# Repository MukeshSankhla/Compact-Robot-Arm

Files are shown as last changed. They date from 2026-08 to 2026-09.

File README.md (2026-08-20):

# ESP32-Controlled 5-Axis Compact Robot Arm

Block Diagram

This project is a high-performance recreation and upgrade of the 3D-printable [Compact Robot Arm (Arduino) by Build Some Stuff](https://www.printables.com/model/818975-compact-robot-arm-arduino-3d-printed). While the original design utilized a passive analog mimic controller, this version leverages the **ESP32** microcontroller coupled with a **PCA9685 16-channel 12-bit PWM driver** to offer dual-mode operation: **tactile physical joystick control** and a **remote WiFi-based web dashboard** featuring a real-time responsive SVG forward-kinematics visualization.

---

## Table of Contents
1. [Key Features](#key-features)
2. [Project Architecture & Directory Structure](#project-architecture--directory-structure)
3. [Bill of Materials (BOM)](#bill-of-materials-bom)
4. [Circuit & Wiring Diagram](#circuit--wiring-diagram)
5. [Pin Mapping](#pin-mapping)
6. [Software Features & Logic](#software-features--logic)
7. [Web Interface & HTTP API](#web-interface--http-api)
8. [3D Printed Parts & Assembly Notes](#3d-printed-parts--assembly-notes)
9. [Getting Started & Installation](#getting-started--installation)
10. [Credits & Attribution](#credits--attribution)

---

## Key Features

- **Dual Control Modes**:
  - **Physical Analog Joysticks**: Tactile manipulation of joints with real-time speed adjustments, plus integrated buttons for quick-closing and opening the gripper.
  - **WiFi Web Dashboard**: Broadcasts an independent Access Point (AP). Hosts a modern, glassmorphism-themed dark-mode dashboard with virtual on-screen joysticks and slider states.
- **Real-Time Visual Representation**: The web interface calculates a 2D side-profile of the robot arm using basic forward kinematics (trigonometric representation of links) and renders it dynamically in a vector-based HTML5 SVG.
- **Smooth Servo Ease Motion**: Prevents violent jerks on startup and during the home command by stepping servo movements incrementally using a custom [`slowMove()`](file:///c:/Users/MAKERBRAINS/Downloads/Compact%20Robot%20Arm/Compact_Robot_Arm_Code/Compact_Robot_Arm_Code.ino#L108) routine.
- **Automatic Calibration**: Automatically samples ADC offsets on boot to establish center positions and deadzones, filtering out joystick noise and drift.
- **Clean Cable Management**: The structural parts are hollow, enabling clean routing of servo motor cables inside the arm segments to avoid twisting and external clutter.

---

## Project Architecture & Directory Structure

```
Compact Robot Arm/
├── BD.png                        # System Block Diagram
├── Circuit Connections.png       # Schematic and Wiring Diagram
├── CAD/                          # 18 STL files for 3D Printing
│   ├── Actuator Support A.stl
│   ├── Actuator Support B.stl
│   ├── Base Rotation Ring.stl
│   ├── Body1.stl
│   ├── Elbow Joint Shaft.stl
│   ├── Elbow Pivot Spacer.stl
│   ├── Forearm Housing Left.stl
│   ├── Forearm Housing Right.stl
│   ├── Gripper Blade A.stl
│   ├── Gripper Blade B.stl
│   ├── Inner Upper Arm.stl
│   ├── Motor Access Plate.stl
│   ├── Outer Upper Arm.stl
│   ├── Servo Mount Plate.stl
│   ├── Shoulder Actuator Case.stl
│   ├── Shoulder Cable Guard.stl
│   ├── Shoulder Mount Plate.stl
│   └── Shoulder Support Plate.stl
├── Compact_Robot_Arm_Code/
│   └── Compact_Robot_Arm_Code.ino # Main Arduino C++ sketch for ESP32
└── README.md                     # Project documentation (this file)
```

---

## Bill of Materials (BOM)

### Electronics
1. **Microcontroller**: ESP32 Development Board (30-pin or 38-pin version).
2. **Servo Controller**: Adafruit PCA9685 16-Channel 12-bit PWM I2C Driver.
3. **Servos**:
   - **4x MG996R (or MG995) metal gear high-torque servos** (for Base, Shoulder, Elbow, and Wrist rotation).
   - **1x MG90S (or SG90) micro servo** (for the Gripper mechanism).
4. **Controllers**: 2x Analog Joystick Modules (e.g., KY-023 dual-axis potentiometer joysticks with integrated push-buttons).
5. **Power Supply**: 5V DC power supply with at least 2A output. Servos drawing current simultaneously under load will cause an ESP32 brownout if underpowered.
---

## Circuit & Wiring Diagram

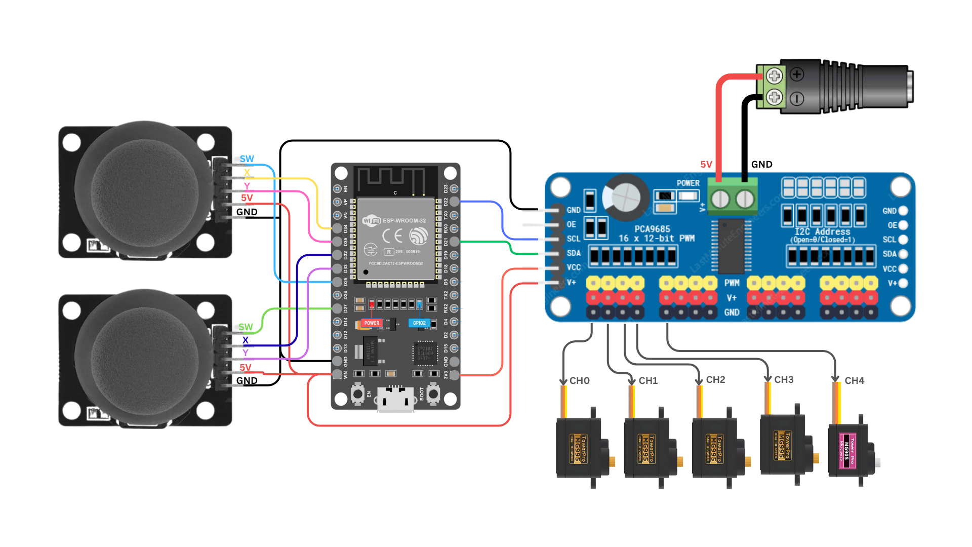
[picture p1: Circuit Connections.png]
Circuit Diagram


---

## Pin Mapping

The physical wiring between the ESP32 microcontroller, Joysticks, and the PCA9685 is configured as follows in the firmware:

### 1. ESP32 to PCA9685 (I2C Communication)
- **SDA** $\rightarrow$ **GPIO 21**
- **SCL** $\rightarrow$ **GPIO 22**
- **I2C Address**: `0x40` (Default)

### 2. PCA9685 Servo Channels
| Channel | Servo Label | Description |
| :---: | :--- | :--- |
| **0** | `M1_CH` | **Base Rotation Servo** (M1) |
| **1** | `M2_CH` | **Shoulder Servo** (M2) |
| **2** | `M3_CH` | **Elbow Servo** (M3) |
| **3** | `M4_CH` | **Wrist Servo** (M4) |
| **4** | `M5_CH` | **Gripper Fingers Servo** (M5) |

### 3. Joysticks to ESP32
| Joystick Module | Joystick Pin | ESP32 GPIO | Associated Action |
| :--- | :---: | :---: | :--- |
| **Joystick 1** | X-Axis | **GPIO 34** | Controls **Shoulder (M2)** |
| **Joystick 1** | Y-Axis | **GPIO 35** | Controls **Base (M1)** |
| **Joystick 1** | Button Switch (SW) | **GPIO 25** | **Opens Gripper** (M5 $\rightarrow$ 90°) |
| **Joystick 2** | X-Axis | **GPIO 32** | Controls **Elbow (M3)** |
| **Joystick 2** | Y-Axis | **GPIO 33** | Controls **Wrist (M4)** |
| **Joystick 2** | Button Switch (SW) | **GPIO 27** | **Closes Gripper** (M5 $\rightarrow$ 0°) |

---

## Software Features & Logic

The project software is loaded in [`Compact_Robot_Arm_Code.ino`](file:///c:/Users/MAKERBRAINS/Downloads/Compact%20Robot%20Arm/Compact_Robot_Arm_Code/Compact_Robot_Arm_Code.ino). Below are descriptions of key functional parts:

### 1. Joystick Calibration ([`calibrateJoysticks()`](file:///c:/Users/MAKERBRAINS/Downloads/Compact%20Robot%20Arm/Compact_Robot_Arm_Code/Compact_Robot_Arm_Code.ino#L156-L205))
On start-up, the ESP32 instructs the user to leave the joysticks untouched for 2 seconds. It takes 100 analog samples from the ADC channels, averages them, and saves the values as references (`J1X_CENTER`, `J1Y_CENTER`, etc.). This calibrates out unique hardware offset errors and centers.

### 2. Noise & Deadzone Filtering ([`joystick()`](file:///c:/Users/MAKERBRAINS/Downloads/Compact%20Robot%20Arm/Compact_Robot_Arm_Code/Compact_Robot_Arm_Code.ino#L212-L239))
Reads the joystick inputs and implements a deadzone filter (`#define DEADZONE 260`) to avoid micro-drifting when the stick is resting. The movement is normalized between `-1.0` and `1.0` using custom scales for asymmetrical potentiometer bounds.

### 3. Ease-in Easing Algorithm ([`slowMove()`](file:///c:/Users/MAKERBRAINS/Downloads/Compact%20Robot%20Arm/Compact_Robot_Arm_Code/Compact_Robot_Arm_Code.ino#L108-L132))
Avoids abrupt servo snap actions. The function divides a large motion request into tiny steps (`stepSize = 0.8f`) separated by micro delays (`msPerStep = 8`), moving the robot smoothly to the target position:
```cpp
void slowMove(uint8_t channel, float fromAngle, float toAngle, float stepSize = 0.8f, int msPerStep = 8)
```

---

## Web Interface & HTTP API

The ESP32 runs a local Web Server on port 80 and initializes an Access Point:
- **SSID**: `RobotArm-ESP32`
- **Password**: `12345678`
- **IP Address**: `192.168.4.1`

### UI Mechanics & Kinematics Engine
- **Canvas Joysticks**: Recreates absolute physical joystick layouts on the screen, bound to click, drag, and touch gestures.
- **Forward Kinematics (SVG Representation)**: In the web script, a 2D side-profile of the robot is drawn using joint lengths (`SEG = [80, 70, 30]`). When servo positions are requested, it updates the SVG elements:
  - Base translation ($M_1$) shifts the base laterally on the page, representing side-view perspective depth.
  - Shoulder ($M_2$), Elbow ($M_3$), Wrist ($M_4$), and Gripper ($M_5$) angles calculate trigonometric relative coordinate positions ($x, y$) for the joint pivots and finger tips, updating the lines and labels live.

### API Endpoints
The server handles the following endpoints:
- `GET /` : Serves the core HTML/CSS/JS page from flash (`MAIN_PAGE`).
- `GET /motor?m=<1-4>&a=<angle>` : Sets a specific joint's target angle (0 to 180 degrees).
- `GET /gripper?action=<open|close>` : Directly commands the gripper servo (90° for open, 0° for closed).
- `GET /home` : Initiates a slow, synchronized homing sequence for all joints.
- `GET /status` : Returns a JSON object containing the current coordinate states:
  ```json
  {"m1": 100.0, "m2": 0.0, "m3": 180.0, "m4": 90.0, "m5": 0.0}
  ```

---

## 3D Printed Parts & Assembly Notes

The custom STL files for the structural parts are stored under the [`CAD/`](file:///c:/Users/MAKERBRAINS/Downloads/Compact%20Robot%20Arm/CAD) directory:
- **Structural arms**: `Inner Upper Arm.stl`, `Outer Upper Arm.stl`, `Forearm Housing Left.stl`, `Forearm Housing Right.stl`
- **Support Plates**: `Shoulder Support Plate.stl`, `Shoulder Mount Plate.stl`, `Servo Mount Plate.stl`
- **Actuators**: `Shoulder Actuator Case.stl`
- **Gripper**: `Gripper Blade A.stl`, `Gripper Blade B.stl`

### Printing Recommendations
- **Material**: PLA 
- **Layer Height**: `0.2 mm`
- **Supports**: Enable support structures for overhang segments.

---

### Firmware Upload
1. Open the [Arduino IDE](https://www.arduino.cc/en/software).
2. Install the **ESP32 board support package** (`Tools > Board > Boards Manager`).
3. Install the **Adafruit PWM Servo Driver Library** from the Library Manager.
4. Open [`Compact_Robot_Arm_Code.ino`](file:///c:/Users/MAKERBRAINS/Downloads/Compact%20Robot%20Arm/Compact_Robot_Arm_Code/Compact_Robot_Arm_Code.ino).
5. Select your ESP32 board and the corresponding COM port.
6. Connect your ESP32 via USB and upload the sketch.

### Initial Boot & Control
1. **Calibrate**: Power on the circuit. Ensure the joysticks are resting centered. The onboard calibration will compute within 2 seconds.
2. **Homing**: The arm will automatically execute a slow home posture sequence to initialize position tracking safely.
3. **Local Control**: Move the physical joysticks to actuate the arm. Press Joystick 1's click switch to open the gripper, and Joystick 2's click switch to close it.
4. **WiFi Control**:
   - On a phone or laptop, scan for WiFi networks and connect to `RobotArm-ESP32` using password `12345678`.
   - Open a browser and navigate to `http://192.168.4.1`.
   - Control the arm using the interactive web dashboard.

---

## Credits & Attribution

- **Original Mechanical Design**: Kelton at [Build Some Stuff](https://www.printables.com/@buildsomestf_1924578).
- **Mechanical CAD/STL files**: Downloaded from the [Compact Robot Arm Printables Page](https://www.printables.com/model/818975-compact-robot-arm-arduino-3d-printed).
- **Firmware, Network Stack, & Web App Upgrade**: Recreated and modified to run on ESP32 + PCA9685 with a visual web server dashboard.

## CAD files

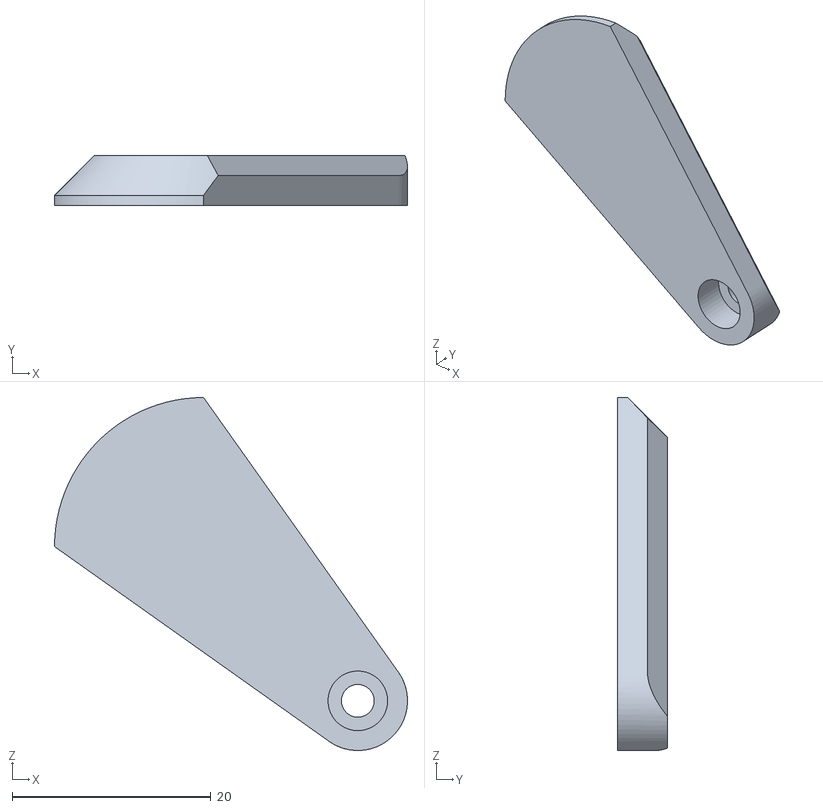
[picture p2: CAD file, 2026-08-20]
CAD/Gripper Blade A.stl
35.5 x 5.00 x 35.5

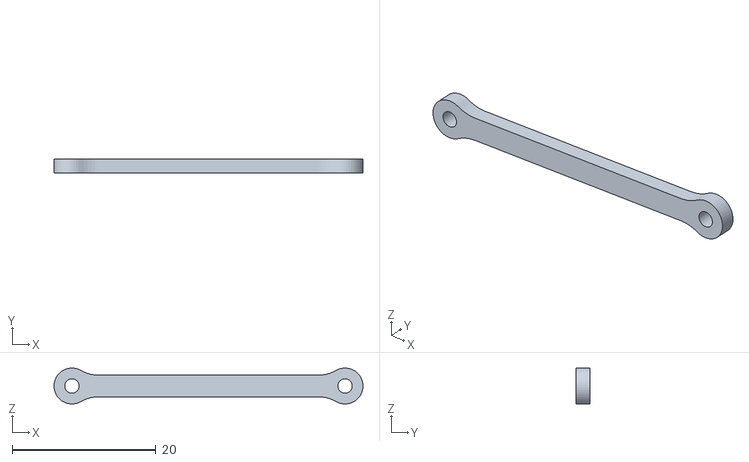
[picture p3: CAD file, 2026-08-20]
CAD/Body1.stl
43.0 x 2.00 x 4.99

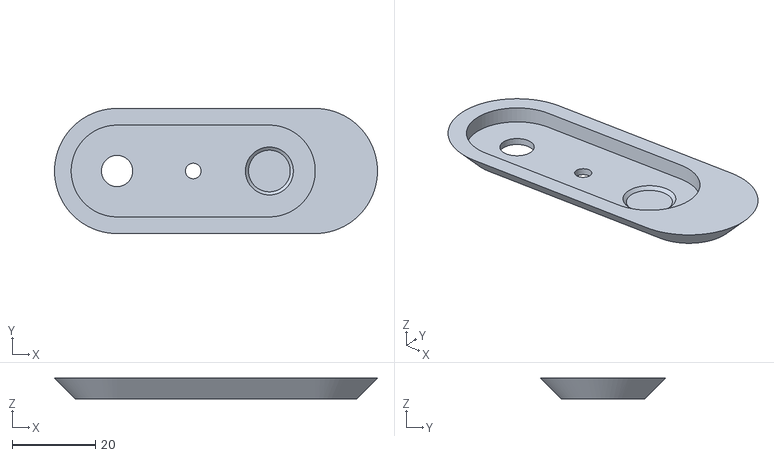
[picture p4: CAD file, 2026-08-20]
CAD/Elbow Pivot Spacer.stl
77.4 x 30.0 x 5.00

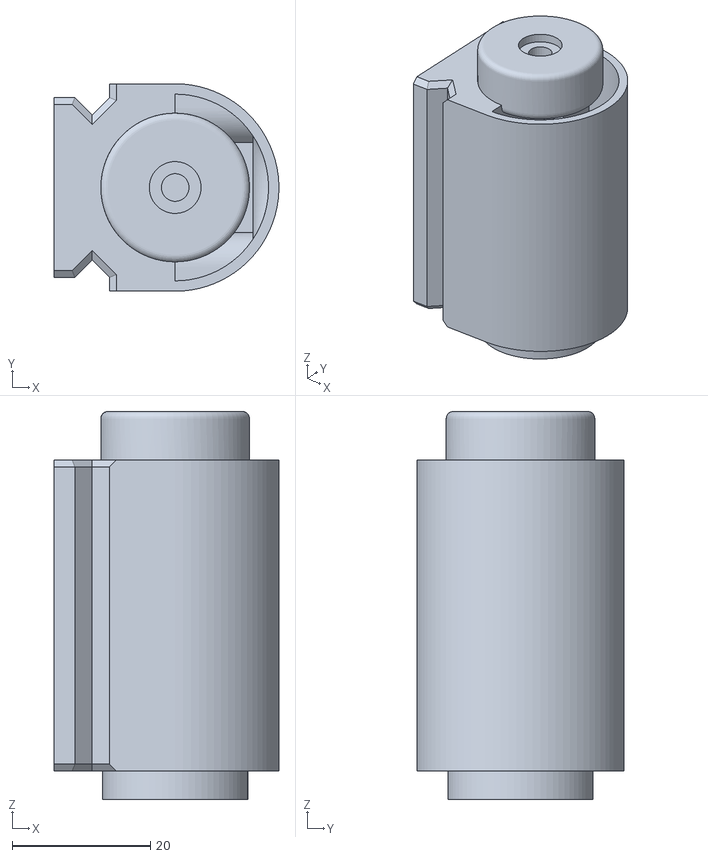
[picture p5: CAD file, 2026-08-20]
CAD/Elbow Joint Shaft.stl
32.5 x 30.0 x 56.1

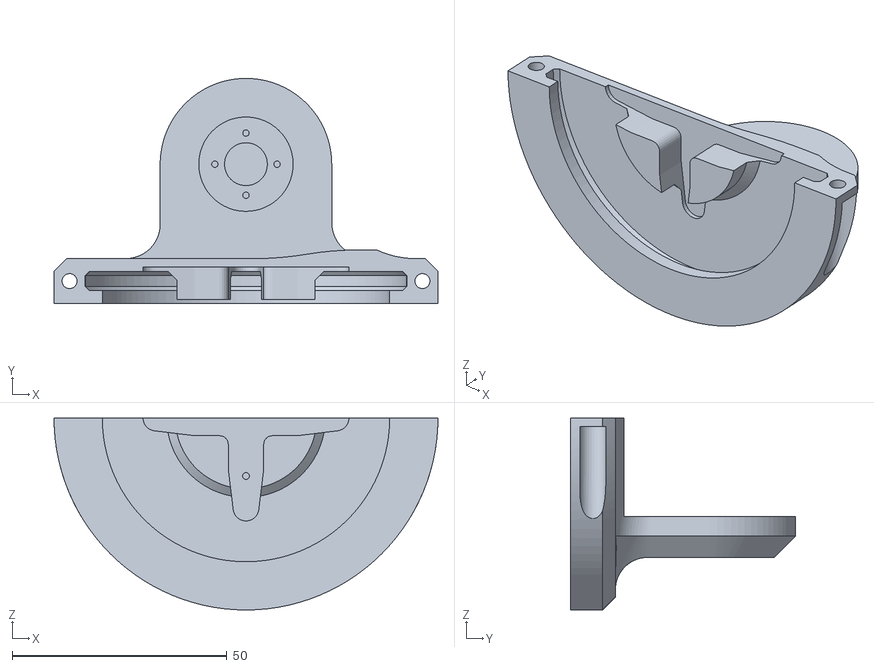
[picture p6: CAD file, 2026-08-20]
CAD/Shoulder Cable Guard.stl
89.5 x 52.5 x 44.8

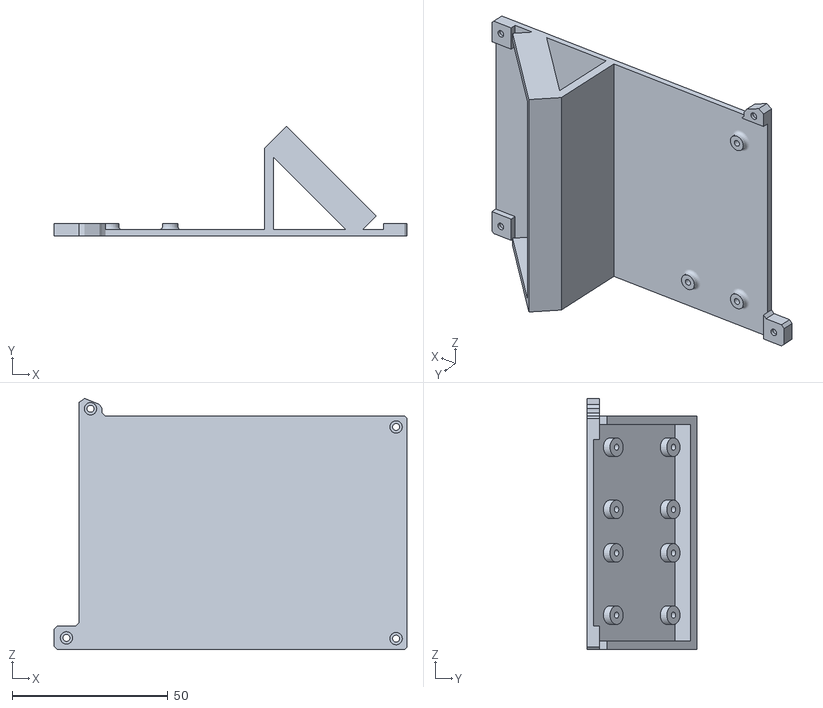
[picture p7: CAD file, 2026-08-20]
CAD/Motor Access Plate.stl
113.5 x 35.2 x 80.7

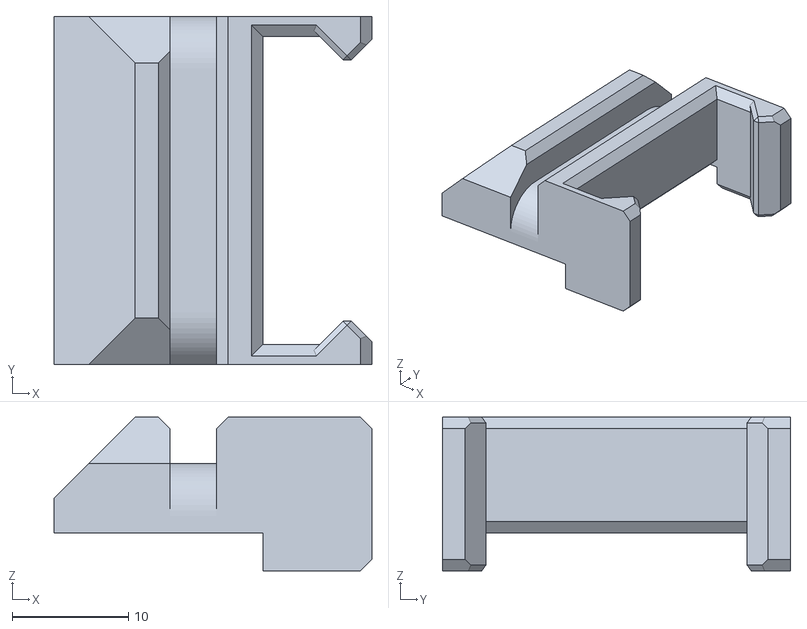
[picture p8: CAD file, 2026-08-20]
CAD/Actuator Support B.stl
27.4 x 30.0 x 13.2

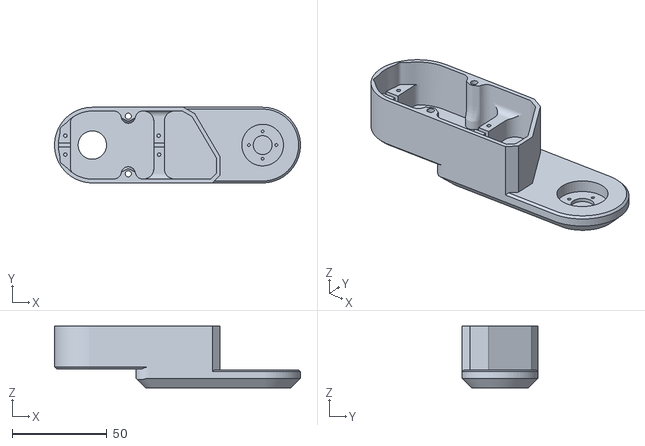
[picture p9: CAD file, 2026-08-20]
CAD/Forearm Housing Right.stl
130.0 x 39.9 x 32.5

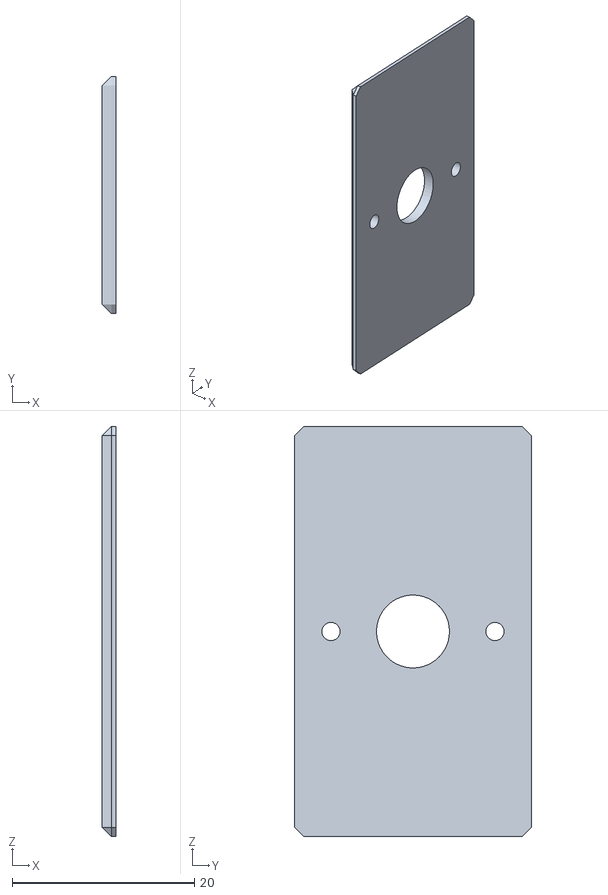
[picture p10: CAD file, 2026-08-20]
CAD/Servo Mount Plate.stl
1.50 x 26.0 x 45.0

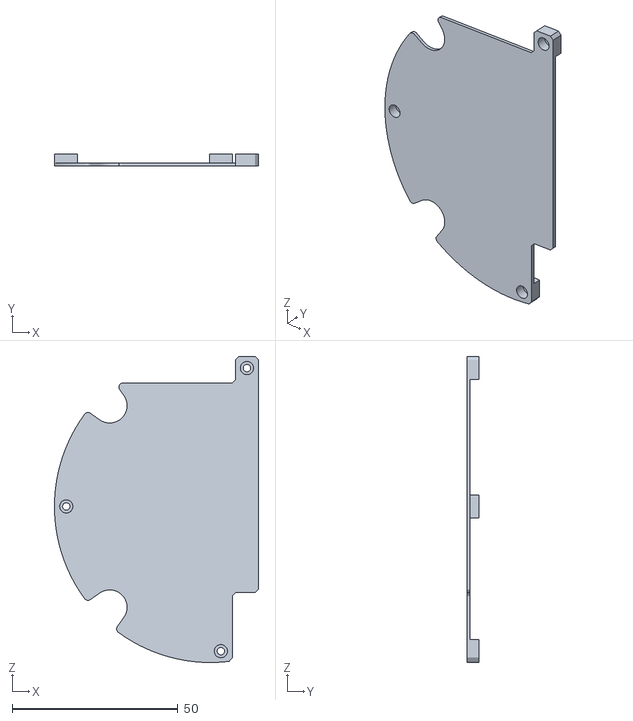
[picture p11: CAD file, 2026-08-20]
CAD/Shoulder Mount Plate.stl
61.6 x 3.75 x 92.4

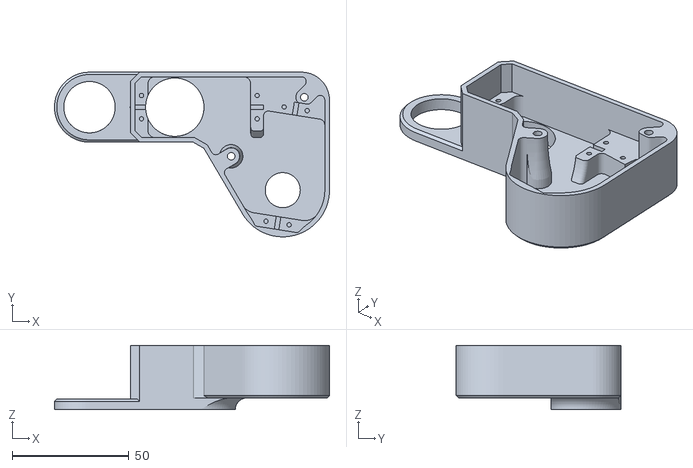
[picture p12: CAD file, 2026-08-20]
CAD/Forearm Housing Left.stl
117.7 x 70.5 x 27.5

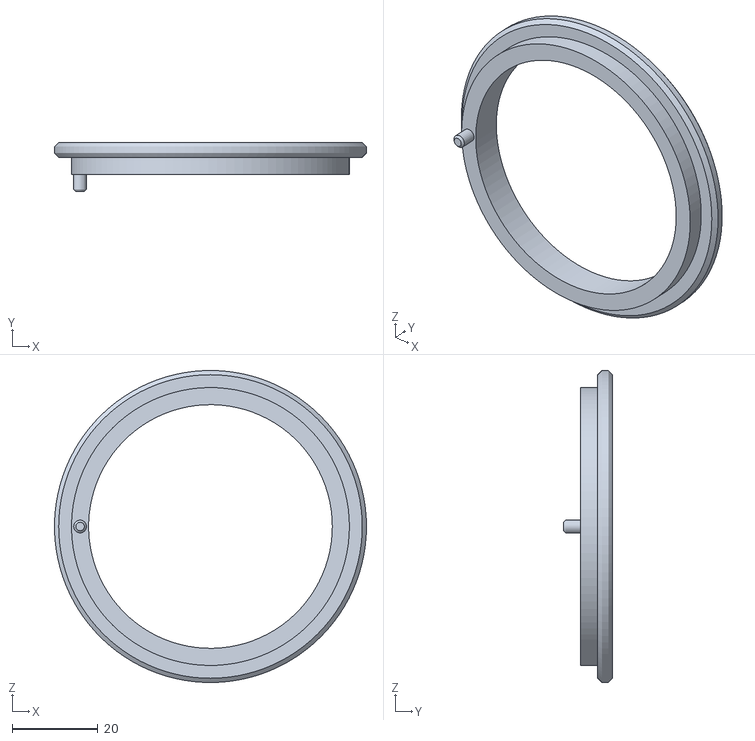
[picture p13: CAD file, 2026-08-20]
CAD/Base Rotation Ring.stl
73.0 x 11.5 x 73.0

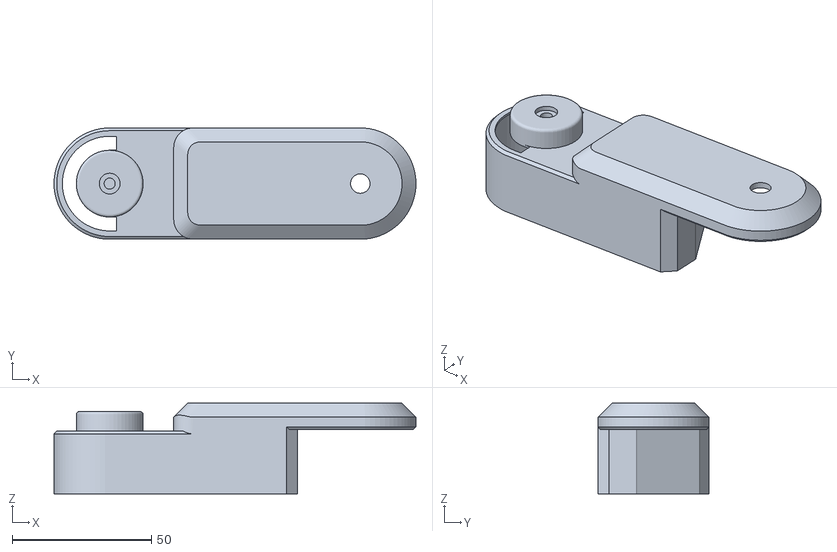
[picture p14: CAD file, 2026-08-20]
CAD/Outer Upper Arm.stl
130.0 x 39.9 x 32.5

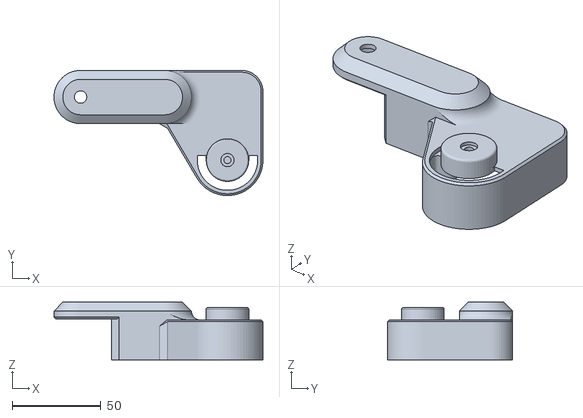
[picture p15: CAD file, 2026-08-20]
CAD/Inner Upper Arm.stl
117.7 x 70.5 x 32.5

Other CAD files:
CAD/Shoulder Support Plate.stl
CAD/Actuator Support A.stl
CAD/Gripper Blade B.stl
CAD/Shoulder Actuator Case.stl

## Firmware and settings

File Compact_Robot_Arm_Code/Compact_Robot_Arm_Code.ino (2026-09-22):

#include <Wire.h>
#include <Adafruit_PWMServoDriver.h>
#include <WiFi.h>
#include <WebServer.h>

Adafruit_PWMServoDriver pwm(0x40);

// =====================================================
// WIFI ACCESS POINT
// =====================================================

const char* AP_SSID     = "RobotArm-ESP32";
const char* AP_PASSWORD = "12345678";

WebServer server(80);

// =====================================================
// PCA9685 CHANNELS
// =====================================================
// M1 = BASE
// M2 = SHOULDER
// M3 = ELBOW
// M4 = WRIST
// M5 = GRIPPER
// =====================================================

#define M1_CH 0
#define M2_CH 1
#define M3_CH 2
#define M4_CH 3
#define M5_CH 4

// =====================================================
// JOYSTICK PINS
// =====================================================
// J1_X -> SHOULDER (M2)
// J1_Y -> BASE     (M1)
// J2_X -> ELBOW    (M3)
// J2_Y -> WRIST    (M4)
// =====================================================

#define J1_X  34
#define J1_Y  35
#define J1_SW 25

#define J2_X  32
#define J2_Y  33
#define J2_SW 27

// =====================================================
// SERVO PWM
// =====================================================

#define SERVO_MIN 150
#define SERVO_MAX 600

#define M4_MIN 70
#define M4_MAX 110

// =====================================================
// HOME POSITION
// =====================================================

float M1 = 100;
float M2 = 0;
float M3 = 180;
float M4 = 90;
float M5 = 0;

// =====================================================
// JOYSTICK CENTER
// =====================================================

int J1X_CENTER;
int J1Y_CENTER;
int J2X_CENTER;
int J2Y_CENTER;

// =====================================================
// JOYSTICK CONTROL
// =====================================================

#define DEADZONE 260
#define SPEED    1
#define SAMPLES  8

// =====================================================
// SERVO FUNCTION
// =====================================================

void setServo(uint8_t channel, float angle)
{
  if (channel == M4_CH)
  {
    angle = constrain(angle, M4_MIN, M4_MAX);
  }
  else
  {
    angle = constrain(angle, 0, 180);
  }

  int pulse = map(
    (int)angle,
    0,
    180,
    SERVO_MIN,
    SERVO_MAX
  );

  pwm.setPWM(channel, 0, pulse);
}


// =====================================================
// SMOOTH SERVO MOVE  (no jumps on power-on / home)
// =====================================================

void slowMove(uint8_t channel, float fromAngle, float toAngle,
              float stepSize = 0.8f, int msPerStep = 8)
{
  if (channel == M4_CH)
  {
    fromAngle = constrain(fromAngle, M4_MIN, M4_MAX);
    toAngle   = constrain(toAngle,   M4_MIN, M4_MAX);
  }
  else
  {
    fromAngle = constrain(fromAngle, 0, 180);
    toAngle   = constrain(toAngle,   0, 180);
  }

  if (fromAngle < toAngle)
  {
    for (float a = fromAngle; a <= toAngle; a += stepSize)
    {
      setServo(channel, a);
      delay(msPerStep);
    }
  }
  else
  {
    for (float a = fromAngle; a >= toAngle; a -= stepSize)
    {
      setServo(channel, a);
      delay(msPerStep);
    }
  }

  setServo(channel, toAngle); // ensure exact final position
}


// =====================================================
// AVERAGED ADC READ
// =====================================================

int readAveraged(int pin)
{
  long sum = 0;

  for (int i = 0; i < SAMPLES; i++)
  {
    sum += analogRead(pin);
  }

  return sum / SAMPLES;
}


// =====================================================
// CALIBRATE JOYSTICKS
// =====================================================

void calibrateJoysticks()
{
  Serial.println();
  Serial.println("=================================");
  Serial.println(" JOYSTICK CALIBRATION");
  Serial.println(" KEEP JOYSTICKS CENTERED");
  Serial.println("=================================");

  delay(2000);

  long sumJ1X = 0;
  long sumJ1Y = 0;
  long sumJ2X = 0;
  long sumJ2Y = 0;

  const int samples = 100;

  for (int i = 0; i < samples; i++)
  {
    sumJ1X += analogRead(J1_X);
    sumJ1Y += analogRead(J1_Y);

    sumJ2X += analogRead(J2_X);
    sumJ2Y += analogRead(J2_Y);

    delay(5);
  }

  J1X_CENTER = sumJ1X / samples;
  J1Y_CENTER = sumJ1Y / samples;

  J2X_CENTER = sumJ2X / samples;
  J2Y_CENTER = sumJ2Y / samples;

  Serial.println();

  Serial.print("J1 X Center (SHOULDER): ");
  Serial.println(J1X_CENTER);

  Serial.print("J1 Y Center (BASE): ");
  Serial.println(J1Y_CENTER);

  Serial.print("J2 X Center (ELBOW): ");
  Serial.println(J2X_CENTER);

  Serial.print("J2 Y Center (WRIST): ");
  Serial.println(J2Y_CENTER);

  Serial.println();
}


// =====================================================
// JOYSTICK MOVEMENT
// =====================================================

float joystick(int pin, int center)
{
  int value = readAveraged(pin);

  int difference = value - center;

  if (abs(difference) < DEADZONE)
  {
    return 0;
  }

  float movement;

  if (difference > 0)
  {
    movement = (float)(difference - DEADZONE)
               / (4095.0 - center - DEADZONE);
  }
  else
  {
    movement = (float)(difference + DEADZONE)
               / (center - DEADZONE);
  }

  movement = constrain(movement, -1.0, 1.0);

  return movement;
}


// =====================================================
// HOME  (smooth – no snapping)
// =====================================================

void home()
{
  // Smooth-move each axis to its home position
  slowMove(M1_CH, M1, 100);  M1 = 100;
  slowMove(M2_CH, M2,   0);  M2 =   0;
  slowMove(M3_CH, M3, 180);  M3 = 180;
  slowMove(M4_CH, M4,  90);  M4 =  90;
  slowMove(M5_CH, M5,   0);  M5 =   0;

  Serial.println();
  Serial.println("HOME POSITION");
}


// =====================================================
// WEB PAGE  – Premium UI
// =====================================================

const char MAIN_PAGE[] PROGMEM = R"rawliteral(
<!DOCTYPE html>
<html lang="en">
<head>
<meta charset="UTF-8">
<meta name="viewport" content="width=device-width, initial-scale=1, maximum-scale=1, user-scalable=no">
<title>5-Axis Robot Arm Controller</title>
<link rel="preconnect" href="https://fonts.googleapis.com">
<link rel="preconnect" href="https://fonts.gstatic.com" crossorigin>
<link href="https://fonts.googleapis.com/css2?family=Inter:wght@300;400;500;600;700&family=JetBrains+Mono:wght@400;600&display=swap" rel="stylesheet">

<style>
  :root {
    --bg:        #07090f;
    --surface:   #0e1117;
    --glass:     rgba(255,255,255,0.04);
    --border:    rgba(255,255,255,0.08);
    --accent:    #00e5ff;
    --accent2:   #7c4dff;
    --green:     #00e676;
    --orange:    #ff9100;
    --red:       #ff1744;
    --text:      #e8eaf6;
    --muted:     #546e7a;
    --radius:    16px;
  }

  *, *::before, *::after { box-sizing: border-box; margin: 0; padding: 0; }

  html, body {
    height: 100%;
    background: var(--bg);
    color: var(--text);
    font-family: 'Inter', sans-serif;
    overflow-x: hidden;
  }

  /* ── Animated background grid ── */
  body::before {
    content: '';
    position: fixed;
    inset: 0;
    background-image:
      linear-gradient(rgba(0,229,255,0.03) 1px, transparent 1px),
      linear-gradient(90deg, rgba(0,229,255,0.03) 1px, transparent 1px);
    background-size: 40px 40px;
    pointer-events: none;
    z-index: 0;
  }

  .page {
    position: relative;
    z-index: 1;
    max-width: 700px;
    margin: 0 auto;
    padding: 16px;
    padding-bottom: 40px;
  }

  /* ── Header ── */
  .header {
    display: flex;
    align-items: center;
    justify-content: space-between;
    margin-bottom: 20px;
    padding: 14px 20px;
    background: var(--glass);
    border: 1px solid var(--border);
    border-radius: var(--radius);
    backdrop-filter: blur(12px);
  }

  .header-title {
    font-size: 1.15rem;
    font-weight: 700;
    letter-spacing: 0.04em;
    background: linear-gradient(90deg, var(--accent), var(--accent2));
    -webkit-background-clip: text;
    -webkit-text-fill-color: transparent;
    background-clip: text;
  }

  .header-sub {
    font-size: 0.7rem;
    color: var(--muted);
    margin-top: 2px;
    font-family: 'JetBrains Mono', monospace;
  }

  .status-badge {
    display: flex;
    align-items: center;
    gap: 7px;
    font-size: 0.72rem;
    color: var(--green);
    font-weight: 600;
    letter-spacing: 0.06em;
  }

  .dot {
    width: 8px; height: 8px;
    border-radius: 50%;
    background: var(--green);
    box-shadow: 0 0 8px var(--green);
    animation: pulse 2s infinite;
  }

  @keyframes pulse {
    0%, 100% { opacity: 1; transform: scale(1); }
    50%       { opacity: 0.5; transform: scale(0.8); }
  }

  /* ── Section label ── */
  .section-label {
    font-size: 0.65rem;
    font-weight: 600;
    letter-spacing: 0.12em;
    color: var(--muted);
    text-transform: uppercase;
    margin-bottom: 8px;
    padding-left: 4px;
  }

  /* ── Glass card ── */
  .card {
    background: var(--glass);
    border: 1px solid var(--border);
    border-radius: var(--radius);
    padding: 16px 18px;
    margin-bottom: 14px;
    backdrop-filter: blur(8px);
    transition: border-color 0.3s;
  }

  .card:hover { border-color: rgba(0,229,255,0.2); }

  /* ── SVG Robot Arm ── */
  #robot-svg-wrap {
    display: flex;
    justify-content: center;
    align-items: center;
    padding: 8px 0 4px;
  }

  #robot-svg {
    width: 100%;
    max-width: 500px;
    height: 200px;
    overflow: visible;
  }



  /* ── Joystick panel ── */
  .joy-panel {
    display: flex;
    justify-content: space-around;
    align-items: flex-start;
    gap: 10px;
    flex-wrap: wrap;
  }

  .joy-block {
    display: flex;
    flex-direction: column;
    align-items: center;
    gap: 8px;
  }

  .joy-title {
    font-size: 0.68rem;
    font-weight: 600;
    color: var(--muted);
    letter-spacing: 0.08em;
    text-transform: uppercase;
  }

  .joy-canvas-wrap {
    position: relative;
    width: 140px;
    height: 140px;
  }

  canvas.joystick {
    border-radius: 50%;
    touch-action: none;
    cursor: grab;
    display: block;
  }

  canvas.joystick:active { cursor: grabbing; }

  .joy-axes {
    display: flex;
    gap: 10px;
    font-family: 'JetBrains Mono', monospace;
    font-size: 0.65rem;
    color: var(--muted);
  }

  .joy-axes span { color: var(--accent); }

  /* ── Gripper ── */
  .gripper-row {
    display: flex;
    align-items: center;
    justify-content: space-between;
    gap: 12px;
    flex-wrap: wrap;
  }

  .gripper-vis {
    display: flex;
    align-items: center;
    justify-content: center;
    width: 80px;
    height: 60px;
  }

  .gripper-svg { overflow: visible; }

  .grip-btn-wrap {
    display: flex;
    gap: 10px;
    flex: 1;
    justify-content: flex-end;
  }

  /* ── Buttons ── */
  .btn {
    border: none;
    border-radius: 12px;
    padding: 13px 22px;
    font-size: 0.82rem;
    font-weight: 700;
    letter-spacing: 0.08em;
    cursor: pointer;
    transition: transform 0.12s, box-shadow 0.2s, opacity 0.2s;
    text-transform: uppercase;
    position: relative;
    overflow: hidden;
  }

  .btn::after {
    content: '';
    position: absolute;
    inset: 0;
    background: white;
    opacity: 0;
    transition: opacity 0.15s;
  }

  .btn:active::after { opacity: 0.12; }
  .btn:active { transform: scale(0.95); }

  .btn-home {
    background: linear-gradient(135deg, #1565c0, #0288d1);
    color: white;
    box-shadow: 0 4px 16px rgba(2,136,209,0.35);
  }

  .btn-home:hover { box-shadow: 0 4px 24px rgba(2,136,209,0.55); }

  .btn-open {
    background: linear-gradient(135deg, #00897b, #00e676);
    color: #07090f;
    box-shadow: 0 4px 16px rgba(0,230,118,0.3);
  }

  .btn-open:hover { box-shadow: 0 4px 24px rgba(0,230,118,0.5); }

  .btn-close {
    background: linear-gradient(135deg, #e65100, #ff9100);
    color: white;
    box-shadow: 0 4px 16px rgba(255,145,0,0.3);
  }

  .btn-close:hover { box-shadow: 0 4px 24px rgba(255,145,0,0.5); }

  /* ── Action bar ── */
  .action-bar {
    display: flex;
    gap: 10px;
    justify-content: center;
    flex-wrap: wrap;
  }



  /* ── Footer ── */
  .footer {
    text-align: center;
    font-size: 0.62rem;
    color: var(--muted);
    margin-top: 20px;
    letter-spacing: 0.06em;
  }

  /* ── Responsive ── */
  @media (max-width: 420px) {
    .joy-canvas-wrap { width: 120px; height: 120px; }
    canvas.joystick { width: 120px !important; height: 120px !important; }
  }
</style>
</head>

<body>
<div class="page">

  <!-- ── HEADER ── -->
  <div class="header">
    <div>
      <div class="header-title">5-AXIS ROBOT ARM</div>
      <div class="header-sub">ESP32 · PCA9685 · WiFi AP</div>
    </div>
    <div class="status-badge">
      <div class="dot"></div>
      LIVE
    </div>
  </div>





  <!-- ── SVG STICK ROBOT ── -->
  <div class="section-label">Robot Visualisation</div>
  <div class="card">
    <div id="robot-svg-wrap">
      <svg id="robot-svg" viewBox="0 0 500 210" xmlns="http://www.w3.org/2000/svg">
        <!-- Grid lines for depth feel -->
        <line x1="0" y1="180" x2="500" y2="180" stroke="rgba(255,255,255,0.06)" stroke-width="1"/>
        <line x1="0" y1="160" x2="500" y2="160" stroke="rgba(255,255,255,0.03)" stroke-width="1"/>

        <!-- Base platform -->
        <rect id="svg-base-plate" x="185" y="178" width="130" height="8" rx="4"
              fill="rgba(0,229,255,0.15)" stroke="rgba(0,229,255,0.4)" stroke-width="1.5"/>

        <!-- Arm segments (drawn via JS) -->
        <line id="svg-seg1" x1="250" y1="178" x2="250" y2="128"
              stroke="#00e5ff" stroke-width="5" stroke-linecap="round"/>
        <line id="svg-seg2" x1="250" y1="128" x2="280" y2="88"
              stroke="#7c4dff" stroke-width="4.5" stroke-linecap="round"/>

        <!-- Gripper lines -->
        <line id="svg-grip1" x1="330" y1="58" x2="340" y2="52"
              stroke="#ff1744" stroke-width="3" stroke-linecap="round"/>
        <line id="svg-grip2" x1="330" y1="58" x2="340" y2="64"
              stroke="#ff1744" stroke-width="3" stroke-linecap="round"/>

        <!-- Joints (circles drawn on top) -->
        <circle id="svg-j0" cx="250" cy="178" r="6" fill="#00e5ff" opacity="0.9"/>
        <circle id="svg-j1" cx="250" cy="128" r="5" fill="#7c4dff" opacity="0.9"/>
        <circle id="svg-j2" cx="280" cy="88"  r="4.5" fill="#ff9100" opacity="0.9"/>

        <!-- In-SVG angle labels (updated by JS) -->
        <g id="svg-labels" font-family="JetBrains Mono,monospace" font-size="8" text-anchor="middle">
          <!-- BASE label -->
          <text id="lbl-base-name" x="250" y="200" fill="#00e5ff" opacity="0.7" font-size="7" letter-spacing="0.04em">BASE</text>
          <text id="tv1"           x="250" y="208" fill="#00e5ff" opacity="0.95" font-weight="bold">100°</text>

          <!-- SHOULDER label -->
          <text id="lbl-shl-name" x="262" y="126" fill="#00e5ff" opacity="0.7" font-size="7">SHOULDER</text>
          <text id="tv2"           x="262" y="134" fill="#00e5ff" opacity="0.95" font-weight="bold">0°</text>

          <!-- ELBOW label -->
          <text id="lbl-elb-name" x="292" y="86"  fill="#7c4dff" opacity="0.7" font-size="7">ELBOW</text>
          <text id="tv3"           x="292" y="94"  fill="#7c4dff" opacity="0.95" font-weight="bold">180°</text>

          <!-- WRIST label -->
          <text id="lbl-wrs-name" x="322" y="65"  fill="#ff9100" opacity="0.7" font-size="7">WRIST</text>
          <text id="tv4"           x="322" y="73"  fill="#ff9100" opacity="0.95" font-weight="bold">90°</text>

          <!-- GRIPPER label -->
          <text id="lbl-grp-name" x="344" y="55"  fill="#ff1744" opacity="0.7" font-size="7">GRIP</text>
          <text id="tv5"           x="344" y="63"  fill="#ff1744" opacity="0.95" font-weight="bold">0°</text>
        </g>

        <!-- Legend -->
        <g font-family="Inter,sans-serif" font-size="8" fill="rgba(255,255,255,0.38)">
          <rect x="6" y="6" width="7" height="7" rx="1" fill="#00e5ff"/>
          <text x="17" y="13">SHOULDER</text>
          <rect x="6" y="18" width="7" height="7" rx="1" fill="#7c4dff"/>
          <text x="17" y="25">ELBOW</text>
          <rect x="6" y="30" width="7" height="7" rx="1" fill="#ff9100"/>
          <text x="17" y="37">WRIST</text>
          <rect x="6" y="42" width="7" height="7" rx="1" fill="#ff1744"/>
          <text x="17" y="49">FINGERS</text>
        </g>
      </svg>
    </div>
  </div>





  <!-- ── VIRTUAL JOYSTICKS ── -->
  <div class="section-label">Virtual Joysticks</div>
  <div class="card">
    <div class="joy-panel">

      <div class="joy-block">
        <div class="joy-title">J1 — Base · Shoulder</div>
        <div class="joy-canvas-wrap">
          <canvas class="joystick" id="joy1" width="140" height="140"></canvas>
        </div>
        <div class="joy-axes">
          X(BASE):<span id="j1xv">0.00</span>&nbsp;
          Y(SHLD):<span id="j1yv">0.00</span>
        </div>
      </div>

      <div class="joy-block">
        <div class="joy-title">J2 — Wrist · Elbow</div>
        <div class="joy-canvas-wrap">
          <canvas class="joystick" id="joy2" width="140" height="140"></canvas>
        </div>
        <div class="joy-axes">
          X(WRST):<span id="j2xv">0.00</span>&nbsp;
          Y(ELBW):<span id="j2yv">0.00</span>
        </div>
      </div>

    </div>
  </div>


  <!-- ── GRIPPER ── -->
  <div class="section-label">Gripper Control</div>
  <div class="card">
    <div class="gripper-row">

      <!-- Mini gripper animation -->
      <div class="gripper-vis">
        <svg class="gripper-svg" id="grip-svg" width="80" height="60" viewBox="0 0 80 60">
          <line x1="40" y1="10" x2="40" y2="38" stroke="#ff1744" stroke-width="4" stroke-linecap="round"/>
          <line id="grip-top"    x1="40" y1="38" x2="60" y2="20" stroke="#ff9100" stroke-width="3.5" stroke-linecap="round"/>
          <line id="grip-bottom" x1="40" y1="38" x2="60" y2="56" stroke="#ff9100" stroke-width="3.5" stroke-linecap="round"/>
          <circle cx="40" cy="38" r="4" fill="#ff1744"/>
        </svg>
      </div>

      <div class="grip-btn-wrap">
        <button class="btn btn-open"  id="btnOpen"  onclick="gripper('open')">⬡ OPEN</button>
        <button class="btn btn-close" id="btnClose" onclick="gripper('close')">⬡ CLOSE</button>
      </div>

    </div>
  </div>


  <!-- ── SYSTEM ── -->
  <div class="section-label">System</div>
  <div class="card">
    <div class="action-bar">
      <button class="btn btn-home" onclick="homeRobot()">⌂ HOME</button>
    </div>
  </div>


  <div class="footer">
    RobotArm-ESP32 · 192.168.4.1 · 5-Axis PCA9685 Controller
  </div>

</div><!-- /page -->


<script>
// ============================================================
// HELPERS
// ============================================================

// ============================================================
// GRIPPER
// ============================================================

function gripper(action) {
  fetch('/gripper?action=' + action)
    .then(() => updatePositions());
  animateGripper(action === 'open');
}

function animateGripper(open) {
  const top    = document.getElementById('grip-top');
  const bottom = document.getElementById('grip-bottom');
  const gap    = open ? 22 : 8;
  top.setAttribute('x2',    '60');
  top.setAttribute('y2',    String(38 - gap));
  bottom.setAttribute('x2', '60');
  bottom.setAttribute('y2', String(38 + gap));
}

// ============================================================
// HOME
// ============================================================
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
void loop()
{
  // ===================================================
  // PROCESS WEB REQUESTS
  // ===================================================

  server.handleClient();


  // ===================================================
  // PHYSICAL JOYSTICK CONTROL
  // ===================================================

  // -------------------------------------------------
  // READ JOYSTICKS
  // -------------------------------------------------

  float j1x = joystick(J1_X, J1X_CENTER);
  float j1y = joystick(J1_Y, J1Y_CENTER);
  float j2x = joystick(J2_X, J2X_CENTER);
  float j2y = joystick(J2_Y, J2Y_CENTER);


  // =================================================
  // J1 X -> M2 SHOULDER (reversed)
  // =================================================

  if (j1x != 0)
  {
    M2 -= j1x * SPEED;
    M2  = constrain(M2, 0, 180);
    setServo(M2_CH, M2);
  }


  // =================================================
  // J1 Y -> M1 BASE (reversed)
  // =================================================

  if (j1y != 0)
  {
    M1 -= j1y * SPEED;
    M1  = constrain(M1, 0, 180);
    setServo(M1_CH, M1);
  }


  // =================================================
  // J2 X -> M3 ELBOW (reversed)
  // =================================================

  if (j2x != 0)
  {
    M3 += j2x * SPEED;
    M3  = constrain(M3, 0, 180);
    setServo(M3_CH, M3);
  }


  // =================================================
  // J2 Y -> M4 WRIST
  // =================================================

  if (j2y != 0)
  {
    M4 += j2y * SPEED;
    M4  = constrain(M4, M4_MIN, M4_MAX);
    setServo(M4_CH, M4);
  }


  // ===================================================
  // J1 BUTTON -> M5 OPEN  (90 deg)
  // ===================================================

  if (digitalRead(J1_SW) == LOW)
  {
    M5 = 90;
    setServo(M5_CH, M5);
    Serial.println("M5 OPEN");
    delay(300);
  }


  // ===================================================
  // J2 BUTTON -> M5 CLOSE  (0 deg)
  // ===================================================

  if (digitalRead(J2_SW) == LOW)
  {
    M5 = 0;
    setServo(M5_CH, M5);
    Serial.println("M5 CLOSE");
    delay(300);
  }


  delay(20);
}

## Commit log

2026-08-20 feat: add CAD models and ESP32 control firmware for the 5-axis robot arm project
    [Actuator Support A.stl, Actuator Support B.stl, Base Rotation Ring.stl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]
2026-08-20 docs: add project README for ESP32-based 5-axis robot arm control system
2026-08-20 docs: embed Block Diagram and Circuit Diagram images in README
